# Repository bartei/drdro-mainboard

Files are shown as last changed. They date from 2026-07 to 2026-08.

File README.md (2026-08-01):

# drDRO Mainboard V1.5




Hardware design **and** firmware for the drDRO 5-axis DRO / motion mainboard —
an STM32F411RET6 board that reads up to five quadrature encoder scales, drives a
step/dir servo axis, and talks to the host over RS-485 or Ethernet.

## The board

4-layer, 178 × 76 mm, 24 V supply (LMR33630 → 5 V → AMS1117 3.3 V). Designed in
EasyEDA Pro (`DRDRO Mainboard V1.5.eprj2`); mechanical model in
`drdro-mainboard.step`, enclosure models under `enclosure/`.

| Subsystem | Hardware |
|---|---|
| MCU | STM32F411RET6 @ 100 MHz (16 MHz HSE), SWD debug |
| Encoder inputs | 5 × DB9, differential RS-422 **or** single-ended TTL (AM26LV32E), hardware quadrature on TIM1–TIM5 |
| Host links | RS-485 (SP3485, USART1 @ 115200) and 10/100 Ethernet (WIZnet W5500 on SPI2 — see the 10BASE-T caveat in `firmware/README.md`) |
| Motor outputs | 3 × STEP/DIR + shared ENA through a ULN2003 (M1 is the servo axis) |
| Digital inputs | 6 × opto-isolated (TLP2309) |
| Analog outputs | 2 × 0–10 V (GP8403 12-bit I²C DAC) |
| Expansion | I²C bus exported on every encoder DB9 |

Design docs, pin map and board status live in `docs/` (`STATUS.md` is the
authoritative hardware state; `mcu_pinmap.md` the pin assignment). `h723_variant/`
holds the design study for a future STM32H723 sibling board.

## The firmware

Complete product firmware under `firmware/` — see
[`firmware/README.md`](firmware/README.md) for the full feature list, protocol
description and build instructions. Highlights:

- FreeRTOS application + dual-bank **IAP bootloader** (A/B storage banks,
  copy-on-activate, power-loss-safe settings, rollback).
- One line protocol (`key=value` + CRC framing) served identically over
  **RS-485 and TCP** (default port 5555, ~250 Hz request rate).
- **Firmware updates over Ethernet** (the running app writes the inactive bank)
  or over RS-485 (bootloader YMODEM — also the recovery path), both driven by
  `firmware/tools/dro_update.py`.
- Host-testable protocol core: `pio test -d firmware/app -e native`.

## Building / flashing

```sh
pip install platformio
pio run  -d firmware/app                 # application (Exec region 0x08020000)
pio run  -d firmware/bootloader          # IAP bootloader (sector 0)
pio test -d firmware/app -e native       # protocol unit tests
firmware/tools/build-release.sh          # firmware/dist/ + merged factory image
```

A blank board is flashed once over SWD with `drdro-mainboard-factory.hex`
(bootloader + app merged). After that, updates need no debugger:

```sh
firmware/tools/dro_update.py --net <board-ip> drdro-mainboard-app.bin   # Ethernet
firmware/tools/dro_update.py /dev/ttyUSB0    drdro-mainboard-app.bin   # RS-485
```

The repo ships a devcontainer (`.devcontainer/`) with the full toolchain,
ST-Link/USB passthrough and host networking — see `.devcontainer/README.md`.

## Releases

Versioning and releases are automated with
[python-semantic-release](https://python-semantic-release.readthedocs.io/) from
[Conventional Commits](https://www.conventionalcommits.org/): every push to
`master` runs the test suite and, if there are releasable changes, tags
`vX.Y.Z`, regenerates [`CHANGELOG.md`](CHANGELOG.md), publishes GitHub release
notes and attaches the firmware assets:

| asset | purpose |
|---|---|
| `drdro-mainboard-app.bin` | application image — feed to `dro_update.py` (automated updates) |
| `drdro-mainboard-app.{hex,elf}` | same image for programmers / debugging |
| `drdro-mainboard-bootloader.{bin,hex,elf}` | IAP bootloader (SWD only) |
| `drdro-mainboard-factory.hex` | merged bootloader + app — first flash of a blank board |
| `SHA256SUMS.txt` | asset checksums |

Pushes to a `dev` branch publish `vX.Y.Z-beta.N` prereleases.

## License

GPL-3.0-or-later — see [LICENSE](LICENSE). The firmware descends from the
[drdro-firmware-f4](https://github.com/bartei/drdro-firmware-f4) baseline.

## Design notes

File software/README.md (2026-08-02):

# drDRO Software (drdro-software-f4)

A **Kivy-based Digital Read-Out (DRO) and single-axis controller UI** for rotary tables,
running on Raspberry Pi or desktop (Linux/Windows/macOS). It drives the **drDRO**
STM32F411 control board ([drdro-firmware-f4](https://github.com/bartei/drdro-firmware-f4))
over RS-485 using the firmware's **custom CLI line protocol** (replacing the older Modbus
RTU stack).

This is the successor to **rotary-controller-python (RCP)** — a 1:1 feature port with the
driver layer swapped to the new protocol, board-side persistent settings, and firmware
updates driven over the same RS-485 bus.

> **This repo is in migration setup.** See `docs/migration_design.md` (verbose design) and
> `docs/migration_todo.md` (phased tracker). Implementation begins after the design review.

---

## Features (target — ported 1:1 from RCP)

- Responsive touch UI built with **Kivy**.
- Communicates over **RS-485** with the drDRO board via its line protocol (115200, auto-direction).
- **Configurable axes** — assign hardware scale inputs, apply transforms (identity / sum).
- **Electronic Lead Screw (ELS)** mode for synchronized threading and power feed.
- **Sync mode** with configurable gear ratios for spindle-synchronized movement.
- **Indexing / Jog / DRO** operating modes; pattern calculators (circle / line / rect).
- Customizable display: fonts, colors, metric/imperial/angle formats.
- Contextual RST help on every setting; WiFi (nmcli) and Pi system maintenance screens.
- **New:** STM32 **firmware update + bank management** over RS-485 (YMODEM), and reliance on
  **board-stored settings** instead of re-pushing config on every reconnect.

---

## Requirements

- **Hardware:** drDRO controller board (firmware: `drdro-firmware-f4`), RS-485 interface,
  Raspberry Pi 3/4/5 for Pi deployments.
- **Software:** Python 3.10+, [`uv`](https://docs.astral.sh/uv/).

## Build & run

```bash
uv sync                       # install dependencies
uv run python -m dro.main     # run the app
uv run pytest                 # run tests
uv build                      # build package
```

---

## Project structure (target)

```
dro/
├── main.py                 # Entry point (asyncio + Kivy event loop)
├── app.py                  # MainApp
├── feeds.py                # Feed/thread pitch tables
├── comms/                  # RS-485 line-protocol driver (replaces Modbus)
│   ├── protocol_client.py  # Framed request/response client (get/set/sta/save/load/...)
│   ├── ymodem.py           # YMODEM sender (firmware push)
│   └── updater.py          # Firmware update + bank management orchestration
├── dispatchers/            # Event dispatchers & state (board, axis, input, servo, els, formats, ...)
├── components/             # UI (screens, home/mode bars, popups, widgets, plot, toolbars)
└── utils/                  # platform.py, kv_loader.py, ctype_calc.py
```

---

## Migrating from rotary-controller-python (RCP)

drDRO software is RCP with the communication layer replaced. If you're coming from RCP:

- **Firmware:** requires the new **drDRO firmware** ([drdro-firmware-f4](https://github.com/bartei/drdro-firmware-f4))
  speaking the RS-485 **line protocol** — it does **not** talk to the old Modbus firmware.
- **No Modbus address:** the bus has a single device and no addressing; `config.ini` no longer
  has a `[device] address` key (just `serial_port` + `baudrate`). `minimalmodbus` is replaced by `pyserial`.
- **Board-stored settings:** servo max/accel/jog now live in the board's flash and are read on
  connect (no re-push every reconnect); the UI writes + `save`s them on change. Sync ratios are
  still computed host-side and pushed live.
- **Config location:** settings now live in `~/.config/drdro-software/` (was
  `~/.config/rotary-controller-python/`). Existing RCP YAML files are not auto-migrated — copy
  them over if you want to keep your axis/format configuration.
- **New: firmware updates from the UI** — the Firmware screen flashes board releases over RS-485
  (Setup → Firmware), and lets you pick the boot bank / reboot the board.

## References

- **Firmware & protocol:** [drdro-firmware-f4](https://github.com/bartei/drdro-firmware-f4)
  (`docs/protocol_design.md`, `dualbank_design.md`, `tools/dro_update.py`).
- **Predecessor:** [rotary-controller-python](https://github.com/bartei/rotary-controller-python).

## License

GPL-3.0-or-later. See `LICENSE`.

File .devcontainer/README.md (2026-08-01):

# Dev container — drDRO mainboard V1.5

VS Code dev container for the firmware in `firmware/`: PlatformIO Core + the
`ststm32`/`stm32cube` toolchain (auto-fetched on first build), a host C compiler,
serial terminals, the GitHub CLI, `st-flash` (raw ST-Link flashing), network tools
for the W5500 bring-up, and the **Claude Code CLI** wired to your host login.

Mirrors the `drdro-firmware-f4` container, with the differences noted below.

## Use
Open the folder in VS Code → **Reopen in Container**. The first build warms the
cache (downloads the `arm-none-eabi` toolchain + framework — a few minutes, once;
cached in the `drdro-mainboard-platformio` volume thereafter).

> **This repo root is not a PlatformIO project.** The firmware lives in
> `firmware/`, next to the hardware design files, so every `pio` command needs
> `-d firmware`. `.vscode/tasks.json` wraps the common ones — **Ctrl+Shift+B**
> builds. If you want the PlatformIO *toolbar* (which keys off a `platformio.ini`
> in the workspace root), open the `firmware/` folder directly instead.

| Task | Command |
|---|---|
| Build | `pio run -d firmware/app` (bootloader: `-d firmware/bootloader`) |
| Flash | `pio run -d firmware/app -t upload`  •  or `st-flash write firmware/app/.pio/build/drdro_mainboard_v15/firmware.bin 0x08020000 (app is Exec-linked; blank boards take firmware/factory.hex)` |
| Clean | `pio run -d firmware/app -t clean` |
| Serial  | `tio /dev/ttyUSB0 -b 115200` — RS-485 debug console (needs a transceiver) |
| Ping | `ping <board-ip>` — the container is on the host network |
| Claude  | `claude` — already signed in with your host account |

Host-side protocol unit tests: `pio test -d firmware/app -e native` (68 cases,
HAL/RTOS mocked under firmware/app/test/mocks/).

## Flashing / debugging (ST-Link over USB)
USB device passthrough is **Linux-host only**. The container runs `--privileged`
with host networking and bind-mounts all of `/dev`, so any USB-connected ST-Link
(and USB-serial adapter) is visible — including devices hot-plugged after the
container started.

The `/dev` bind mount only *exposes* the host's device nodes; it does not change
their permissions. So the udev rule must exist on the **host**. `49-stlink.rules`
in this folder is the one in use on this machine (already installed at
`/etc/udev/rules.d/49-stlink.rules`); on a fresh host:

```sh
sudo cp .devcontainer/49-stlink.rules /etc/udev/rules.d/
sudo udevadm control --reload-rules && sudo udevadm trigger
```

PlatformIO's own `99-platformio-udev.rules` works equally well if you prefer it.

`setup.sh` reports ST-Link status at container-create time, so a missing rule or
an unplugged probe is obvious immediately rather than at first flash.

### WSL
The ST-Link must be attached to WSL from Windows first (admin PowerShell):

```powershell
usbipd list
usbipd attach --wsl --busid <BUSID>   # --auto-attach survives replug/probe reset
```

### OpenOCD transport quirk (already handled)
`ststm32@19.4.0` hardcodes `transport select hla_swd`, but the OpenOCD it pins
(0.12) dropped the legacy HLA driver, so a stock `-t upload` fails with
*"Debug adapter doesn't support 'hla_swd' transport"*. `firmware/support/
openocd_swd_transport.py` rewrites that one flag at upload time, so this is
transparent here — no need for the `stlink-tools` fallback. See that script's
header for why the platform pin is kept rather than bumped.

## Claude Code
`claude` is installed in the image (native standalone build, in `~/.local/bin`) and
the container **bind-mounts your host `~/.claude` and `~/.claude.json`**. That means
it shares the host's login (`~/.claude/.credentials.json`), settings, global
`CLAUDE.md`, and memory — no separate `/login` inside the container.

- Sharing works because the container's `vscode` user is uid 1000, matching the host
  user, so the mounted config files are owned correctly.
- `DISABLE_AUTOUPDATER=1` stops the container's claude from self-updating and
  rewriting the shared host config; update Claude on the host as usual.
- Because the config is *shared* (not copied), sessions/history from the container
  land in your host `~/.claude`.

## Ethernet bring-up notes
`--network=host` puts the container on the real LAN, so once the board has its DHCP
lease you can `ping` it and run `tcpdump` against the same segment — both installed.

Remember the hardware finding: **this W5500 only receives at 10 Mbps**, so a
10BASE-T-capable switch must be in the path. Full measurements in
`firmware/README.md`.

## How it's wired
- `Dockerfile` — base image + apt tools (compiler, serial, lrzsz, usbutils,
  **stlink-tools**, **iputils-ping/tcpdump**) and the **Claude Code** native install
  for the `vscode` user.
- `devcontainer.json` — `--privileged` + `--network=host`, `/dev` bind mount, host
  `~/.claude`/`~/.claude.json` bind mounts, and the PlatformIO extension pinned to
  the volume's CLI core.
- `setup.sh` (postCreate) — installs PlatformIO Core to `~/.platformio/penv`, warms
  the build **and pre-fetches `tool-openocd`** (otherwise first discovered at first
  flash), then reports claude / st-flash / ST-Link status.
- `~/.platformio` is the named volume `drdro-mainboard-platformio` — deliberately
  **separate** from the f4 project's `drdro-platformio` so the two cannot disturb
  each other's pinned packages.

## PlatformIO extension note
`platformio-ide.customPATH` points the extension at the CLI core installed in the
`~/.platformio` volume, and `useBuiltinPIOCore=false` stops it from downloading and
installing its *own* core on open — which otherwise races the `setup.sh` install and
triggers the "installing PlatformIO Core…" prompt on every container open.

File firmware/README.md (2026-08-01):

# drDRO mainboard V1.5 — firmware

Full firmware for the **STM32F411RET6** on the DRDRO Mainboard V1.5 (the board in
this repo): PlatformIO + STM32Cube HAL + FreeRTOS. Ported from the proven
`drdro-firmware-f4` baseline (the previous, RS-485-only board) and extended with
this board's hardware: 5 encoder scales, W5500 Ethernet (TCP CLI + network
firmware updates), GP8403 analog outputs, and 6 opto-isolated inputs.

## Layout — two PlatformIO projects + a shared contract

```
firmware/
├── app/          the application  (Exec region 0x08020000, FreeRTOS, all features)
├── bootloader/   IAP bootloader   (sector 0 @ 0x08000000, polled, self-contained)
├── shared/       app<->bootloader contract: Bootloader.h (flash map + handshake),
│                 Settings.h ("DRO2" persisted layout), BlinkCode.h, BoardPins.h
├── tools/        dro_update.py (serial + --net updater), make_factory.py,
│                 build-release.sh
└── reference/    TEMPORARY copy of drdro-firmware-f4 (gitignored, never commit)
```

## Build / flash / test

```sh
pio run  -d firmware/app                    # build the app
pio run  -d firmware/bootloader             # build the bootloader
pio run  -d firmware/app -t upload          # flash the app over ST-Link (SWD)
pio test -d firmware/app -e native          # host-side protocol unit tests (68)
firmware/tools/build-release.sh             # dist/ artifacts + merged factory.hex
```

A blank board gets the merged `factory.hex` (bootloader + app in one image);
after that, updates go through the dual-bank IAP cycle — no ST-Link needed:

```sh
# over Ethernet (the running app writes the inactive bank; ~30 s):
firmware/tools/dro_update.py --net <board-ip> firmware/app/.pio/build/drdro_mainboard_v15/firmware.bin

# over RS-485 (bootloader YMODEM; also the recovery path):
firmware/tools/dro_update.py /dev/ttyUSB0 firmware/app/.pio/build/drdro_mainboard_v15/firmware.bin
```

## Features / interfaces

- **CLI line protocol** — identical wire format on both transports
  (`cmd [args]\r` in; `key=value` lines + `crc=HH` + blank line out; optional
  `*HH` request checksum; empty line repeats the last command):
  - **RS-485**: USART1 @ 115200 8N1, DE on PA11 (asserted per response, released
    on the TC interrupt).
  - **TCP**: port `net.port` (default **5555**), one client at a time. DHCP by
    default; static IP via `net.dhcp=0` + `net.cfg.*` (applied at next boot).
- **Commands**: `sta get set settings save load bank rollback version help
  update reset dout fw.begin fw.status fw.commit fw.abort`
- **Registry**: `scales.pos/speed/num/den/sync/filt/dir` (×5),
  `servo.max/acc/jog/idx/mode/pos/speed/tgt`, `din.state/cnt/deb`,
  `aout.raw` (×2, 0..4095 = 0..10 V), `net.*`, `diag.cycles/interval/cycmax/uptime`
  (cycle counts are DWT ticks @ 100 MHz = 10 ns; `set diag.cycmax 0` re-arms the
  worst-case hold; uptime as `<days>d<HH>:<MM>:<SS>`).
- **Encoders**: 5 hardware-quadrature scales on TIM1..TIM5. The AM26LV32E
  receiver inversion is fixed in `Scales.c` (IC1 polarity); `scales.dir` is the
  user-level flip.
- **Motion**: single step/dir servo axis (M1, TIM9 100 kHz RAM-resident ISR —
  survives flash writes); shared ENA; M2/M3 pins exercisable via `dout`.
- **Updates**: dual-bank copy-on-activate (see `shared/Bootloader.h` for the
  flash map). Ethernet updates stream into the inactive bank on port
  `net.port+1` and only `fw.commit` (full-size + CRC32 + vector checks) can
  activate it; the UART-only bootloader (YMODEM) is the recovery path.
- **LED** (PA12): blink codes — 1 app running / 2 bootloader / 3 network down /
  4 W5500 error / 5 flash fault (`shared/BlinkCode.h`).

## Hardware caveat

The W5500 on this board only *receives* at **10BASE-T** (verified per-mode on
hardware; see `app/README.bringup.md` for the measurement). `Net.c` forces
10M-half first and a 10 Mbps-capable switch is required.

## Baseline / history

- `app/README.bringup.md` — the original Ethernet bring-up notes (clock/SPI/
  DHCP verification, PHY-mode measurements, MACRAW self-test).
- The `drdro-firmware-f4` project is the design baseline; its docs
  (`protocol_design.md`, `dualbank_design.md`) still describe the protocol and
  bank machinery authoritatively. Differences here: 5 scales (registry arrays
  are 5 wide), settings magic **DRO2** (fresh payload, same frozen core), DE
  pin handling, TCP transport, `dout`/`fw.*`/`din.*`/`aout.*`/`net.*`, and a
  version-stamped bootloader (`BL_VERSION`).

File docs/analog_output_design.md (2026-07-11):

# Analog outputs — 2× 0–10 V for VFD speed reference

## Goal
Add **two 0–10 V analog outputs** to command spindle/motor RPM on variable-frequency
drives (VFD analog speed reference). Decided **2026-07-10**. **4–20 mA was
considered and dropped** (user, 2026-07-10) — 0–10 V only. Non-isolated (board and
VFD share the cabinet 0 V), cost/JLCPCB-stock prioritized.

## Part of record
**U20 (next free designator — confirm in EDA) = GP8403-F50-NF-EW** (Guestgood /
客益微), ESSOP-10-150mil, **JLCPCB/LCSC C3152007** (~$1.70@1, ~4.9k stock 2026-07-10
— re-verify JLCPCB SMT stock/part-class at order time, changes daily).

Dual 12-bit I²C→analog-voltage DAC: **one chip = both channels**. 0–5 V / 0–10 V
range software-selectable. 0.5% output error (0.2% "H" grade exists if ever needed).
Response time ~100–200 µs. Each VOUT sources up to 20 mA.

### Why this part
- **STM32F411 has no internal DAC** (unlike F410/F407) — an external device is
  required no matter what; this is the tidiest one.
- **24 V-native**: VCC range 10–40 V (nom 12 V, tested at 24 V). Runs straight off
  the board's existing 24 V rail — no new supply, no op-amp gain stage, no
  PWM+filter ripple/settling tuning.
- Dual channel in one small SO-package; cheap and well-stocked on JLCPCB.
- Alternatives rejected: **DAC8760/AD5420** (does 0–10 V *and* 4–20 mA in one chip,
  but ~2–3× cost + extended-part stock risk — overkill once 4–20 mA was dropped);
  **PWM (TIM9 CH1/CH2 = PA2/PA3) + RC filter + op-amp** (cheapest silicon but adds a
  filter+RRO-op-amp stage per channel, ripple/settling trade, more board area than
  the GP8403 for ~the same cost).

## Supply
- **VCC ← 24 V rail.** Add local decoupling: 0.1 µF + 10 µF at the pin. The raw 24 V
  bus carries motor-driver switching noise → add a **series ~10 Ω (or ferrite) + 10 µF
  RC** feeding the DAC VCC to keep that noise off the reference. (5 V/3V3 rails are
  too low — the part needs ≥10 V.)
- **V5V pin**: internal 5 V LDO output — needs an external **≥1 µF** cap to GND
  (datasheet requirement).

## Digital interface (I²C) — DECIDED: shared I²C1 expansion bus (2026-07-10)
- **On the existing I²C1 expansion bus** (PB8 SCL / PB9 SDA), shared with the five
  DB9 connectors' pin 5/9. U20-1 SCLK→SCL, U20-2 SDA→SDA. **No new GPIO used.**
  - Pull-ups: **existing R74 (SCL) / R14 (SDA) 4.7 kΩ → 3V3** — reused, none added.
  - I²C logic high 2.7–5.5 V → 3.3 V MCU drive is in spec.
  - **Address = 0x58** (A0/A1/A2 all strapped to GND). **Reserve 0x58** — no future
    DB9-bus expansion device may reuse it.
  - Trade-off accepted: the AO DAC shares a bus routed out to 5 external connectors,
    so a field short on a DB9 pin 5/9 could disturb DAC comms. Acceptable — the DAC
    holds its last output and a 0–10 V speed ref is not safety-critical here.
- **Rejected alternative:** dedicated bit-bang bus on 2 spare GPIOs (PC8/PC9) for
  isolation from the external bus. Cleaner electrically but costs 2 pins + firmware;
  user chose the shared bus for simplicity (pull-ups already present).

## Analog outputs
- VOUT0 → **AO0**, VOUT1 → **AO1** (as-built net names).
- **Per output**: **1 µF** cap to GND (C42/C43) **+ 12 V unidirectional TVS to GND**
  (**SMAJ12A**, JLCPCB **C113957**, SMA/DO-214AC — same TVS family already used on
  the board; cathode→signal, anode→GND). 12 V standoff clears the 0–10 V signal and
  clamps (~19.9 V) well under the 40 V abs-max. **Cap value per the official (Chinese)
  datasheet pin table: 1 µF on each VOUT, >1 µF on V5V** — as-built 1 µF is correct.
  (The third-party English "StanStrong" translation says 10 µF; it's wrong — official
  source governs.)
- **47 Ω series R** to the terminal for short/surge hardening (R75/R76) — VFD analog
  inputs are high-Z (≥10 kΩ typ) so the divider error is negligible. TVS + cap sit on
  the DAC side, series R between them and the connector.
- **Connector**: **CN9**, 4-pos terminal block, **WJ15EDGRC-3.81-4P** (matches
  existing connectors) — **AO0 / AO1 / GND / GND** (pin4/3 = outputs, pin1/2 = COM).
  Wiring to VFD: AOx → analog-in (AI/VI), COM → analog-common (ACM/GND). Non-isolated:
  COM = board GND.

## Range / resolution / accuracy
0–10 V, 12-bit → **2.44 mV/LSB**, 0.5% total error, 50 ppm/°C, ~200 µs settle.
Far finer than any VFD speed-reference needs.

## Firmware notes
- **Set 0–10 V mode once** at boot: config register (addr byte **0x01**), write
  **0x11** (0x00 = 0–5 V). Optionally persist to on-chip NVM (§3.3.7) so it survives
  power-down.
- **Write a channel**: VOUT0 via command **0x02**, VOUT1 via **0x04**; 12-bit code
  as two bytes (low byte first, low 4 bits of the low byte ignored — i.e. code is
  left-justified). Output: **VOUT = DATA/0xFFF × 10 V**.
- Scale spindle RPM setpoint → 12-bit code per VFD's max-RPM-at-10 V setting.

## Board impact (as-built, `Netlist_Schematic1_2026-07-10.net`)
+1 IC (U20 GP8403), passives: C42/C43 1 µF out, D5/D6 SMAJ12A TVS, R75/R76 47 Ω
series, C45 1 µF V5V (+ VCC decoupling), +1 terminal block (CN9). **0 new MCU GPIO**
(shares I²C1 PB8/PB9; pull-ups R14/R74 reused). Component count 177 → **189**.

## AS-BUILT — verified 2026-07-10 (netlist review)
U20 = GP8403-TC50-EW (C3152007). VCC→VIN (24 V, D2/U2 source); GND + **EP→GND** ✓;
SCLK/SDA→SCL/SDA (I²C1 + DB9 pin5/9 + R74/R14); **A0/A1/A2→GND = addr 0x58**;
V5V→C45(1 µF); VOUT0→AO0, VOUT1→AO1, each C(1 µF)+SMAJ12A(→GND)+47 Ω→CN9
(AO0/AO1/GND/GND). No dangling nets; 3V3/5V/VIN all sourced. **Clean.**
Open (optional): local 0.1 µF + RC/ferrite on VCC to keep 24 V-bus switching noise
off the reference; reserve I²C **0x58** against future DB9-bus devices.

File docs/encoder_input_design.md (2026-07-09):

# Encoder input stage — universal single-ended + differential

## Goal
Accept BOTH single-ended TTL and differential RS-422 encoder/scale inputs on
the same DB9, with **no mux and no mode selection** — "just works" like the
cheap Chinese DROs. Approved 2026-07-04.

## AS-BUILT vs TARGET (status 2026-07-09)
**As built** (netlist `Netlist_PCB1_2026-07-09.net`, verified): the mux is gone,
the biased-receiver technique is in, and the **per-DB9 split is DONE — 5 quad
receivers, one AM26LV32EIDR at each connector, A/B only**:
- U7 = J1/ENC1, U8 = J2/ENC2, U9 = J3/ENC3, U10 = J4/ENC4, U11 = J5/ENC5
- Per line: 2.2k pull-up on A+/B+, 2.2k/2.2k divider on A−/B− (~2.5V ref), no term
- Receivers enabled (pin4/G = 3V3); each chip's 2 spare channels have inputs tied
  to a defined level, outputs left open
- Receiver outputs direct to MCU (PA8/9, PA5/PB3, PA6/7, PB6/7, PA0/1 → TIM1–5).
  **No index-Z wired yet.**

**Remaining vs design of record:** only **index-Z** is still to add (A/B/**Z** +
spare per the "Modularity" section below). Reuse a spare receiver channel per chip
for Z; DB9 pin 6 is the only free connector pin (see Z-routing constraint).

**Z-routing constraint:** each DB9 (DS1037-09) has only **pin 6** free — pins
5/9 carry the I²C SCL/SDA expansion bus. So a *differential* Z (Z+/Z−) has no
room unless I²C is dropped/moved; a **single-ended Z on pin 6** is the drop-in
option. MCU side is not the limit: 11 free GPIOs (PC13/14/15, PA2/3/4, PC8/9,
PD2, PB4/5) — ample for 5 Z inputs. Tracker: `encoder_input_todo.md`.

## Decision
Replace the current dual-path front-end (AM26LV32E differential receiver +
NC7SZ157 mux + TTL_SEL) with a **single universal biased differential
receiver** per channel, no termination, no mux.

### The technique (industry-standard; see references)
A differential line receiver reads single-ended by biasing the complementary
(−) input to a fixed reference at **half the encoder supply (2.5 V for 5 V
scales)**, per Emerson/Control Techniques CTTN #155 ("bias the complementary
channels... to ½ of the encoder supply") and confirmed by TouchDRO ("RS-422
line receivers also handle single-ended quadrature inputs cleanly").

Per differential pair (e.g. A+/A−):
- **A+ → pull-up to 5 V** (fail-safe high when idle; also serves open-collector
  single-ended scales)
- **A− → divider to ~2.5 V reference** (½ of the 5 V scale supply)
- **NO termination** (the old 120 Ω is what collapsed the reference and forced
  the mux; low-Z termination breaks single-ended — CTTN #155 disables term in
  this mode)
- optional **~150 Ω series** resistor from the DB9 pin for ESD/fault protection

Behaviour, all with one input, no switching:
| Scale | A+ | A− | Receiver sees | Output |
|---|---|---|---|---|
| Single-ended | 0–5 V signal | 2.5 V ref | signal vs 2.5 V | clean ✓ |
| Differential | driven | driven (low-Z driver **overrides** the kΩ bias) | true differential | clean, full CMRR ✓ |
| Disconnected | pulled to 5 V | 2.5 V | +2.5 V | defined HIGH → no phantom counts ✓ |

The differential driver "takes over" the − line because the bias is high-Z
(kΩ) and the line driver is low-Z. That's the whole trick.

### Receiver part: AM26LV32E (keep) — confirmed right
Quad differential line receiver, already in the design. Datasheet SLLS849E:
- A/B input abs-max **±14 V** → rugged for external DB9 (miswire/ESD/any scale)
- VIH to **5.5 V**, common-mode **−7…+7 V** → handles 2.5 V bias + 5 V swing
- **3.3 V supply, 3.3 V logic output** → safe for ALL MCU pins incl. **PA0
  (ENC5A), which is 3.3 V-only/not 5 V-tolerant**. A 5 V receiver (AM26C32/
  26LS32) would over-drive PA0 → rejected for that reason.
- Failsafe ("E" variant).

### Modularity: one quad receiver per DB9 connector
Go **one AM26LV32E per DB9** (5 chips vs current 3):
- Self-contained per-axis block → copy-paste schematic + PCB, better layout.
- Receive differential AT the connector → best signal integrity.
- Per-axis fault isolation.
- Quad = A + B + **Z (index)** + 1 spare → future-proofs the reference mark
  (DRO homing) with no redesign. Currently only A/B wired.
- Tie spare channel inputs to a defined level.

### Open detail — bias divider vs receiver input R
AM26LV32E input resistance is 4–17 kΩ, which loads the 2.5 V divider (a naive
10 k/10 k sags to ~1.9 V). Fix when specing values: use a stiffer divider
(~2.2 k/2.2 k) OR one shared buffered 2.5 V reference fed through per-channel
series R. Reference anywhere ~2.0–2.5 V is fine (0–5 V swing gives margin).

## Parts removed vs current design
- NC7SZ157 muxes (U22–U31, all 10) — deleted
- 1 kΩ I0 series resistors (R78 ×10) — deleted
- 120 Ω terminations (R47 ×10) — deleted
- TTL_SEL GPIO (PA4) — freed
- Route AM26LV32E outputs directly to the MCU encoder pins.

## Caveat (inherent to single-ended, per CTTN #155)
Single-ended has no common-mode rejection on that channel → more noise-
sensitive than differential. Good grounding/shielding matters. A differential
scale on the same input still gets full noise rejection. This is the exact
trade-off cheap DROs accept.

## References
- Emerson/Control Techniques CTTN #155 "Accommodating Single Ended Encoders"
- TouchDRO glass-scale resources (touchdro.com)
- TI AM26LV32E datasheet SLLS849E

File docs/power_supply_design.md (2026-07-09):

# Power supply — 24V → 5V buck stage

## Decision

Replace the LM2596-5.0 with a **TI LMR33630ADDAR** synchronous buck converter
(HSOIC-8 PowerPAD, adjustable output, 400 kHz).

## Why this part

- **3.8–36 V input range** — large margin above the 24 V nominal rail. The
  board is a motion-control mainboard (rotary/servo), so the 24 V bus likely
  carries switching noise from motor drivers; 36 V abs-max headroom absorbs
  that without derating the part right at its ceiling (unlike parts rated
  only to 24–28 V).
- **Synchronous topology** (no catch diode) — peak efficiency >95%, far above
  the LM2596's typical ~75–85% at 24V→5V/2A.
- **3 A rated device vs. 2 A max load** — ~33% continuous-current headroom,
  keeps thermal/transient margin comfortable.
- **400 kHz switching** allows an 8–10 µH inductor and ceramic-only output
  caps, vs. the LM2596's typical 33–100 µH inductor + electrolytic bulk caps.
  Meaningful footprint reduction.
- **Internally compensated** — no external compensation network, minimal
  part count.
- Confirmed **not deprecated**, in active production.

## Stock verification (checked 2026-07-03, JLCPCB SMT-assembly inventory — verify again before ordering, this changes daily)

| Part | Role | JLCPCB # | Stock | Class | Notes |
|---|---|---|---|---|---|
| LMR33630ADDAR (TI) | Buck controller | C841384 | 9,995 | Extended | 3.8–36V in, 3A, 400kHz, HSOIC-8 PowerPAD |
| CYA0630-10UH (SHOU HAN) | Power inductor | C5189958 | 66,769 | Extended | 10µH, 4A rated / 5.5A sat, 71mΩ DCR, 7.2×6.6mm shielded |
| TPS54331DR (TI) | Fallback controller (alt) | C9865 | 94,107 | Extended | Non-sync alt, see below |

Other LMR33630 variants checked and rejected for this design:
- `LMR33630BDDAR` (1.4MHz) — C544370, only 1,835 units. Usable if board space
  later forces a smaller inductor, but thinner stock margin.
- `LMR33630CDDA` (2.1MHz) — out of stock at time of check.
- `MP2315`/`MP2338` (MPS) — not carried on LCSC/JLCPCB under the genuine MPS
  brand, or Vin range (≤24-28V) leaves no headroom over the 24V nominal rail.
- CENKER `CKCS5040-8.2uH/M` inductor — only 410 units and flagged "not
  recommended for new designs" on JLCPCB. Avoided.

## Design equations used (LMR33630 datasheet §9.2.2, SNVSAN3F)

- FB divider: `RFBB = RFBT / (VOUT/VREF − 1)`, VREF = 1.0 V nominal.
  Base point RFBT = 100 kΩ → RFBB = 24.9 kΩ for VOUT = 5 V (both 1%). This
  was superseded by the adjustable divider below, kept here for reference.
- Adjustable divider (4.8–5.2V range): solved the two endpoint equations
  simultaneously against a 2kΩ trim span (`RFBB_min = 9.5·Rtrim`,
  `RFBT = 4.2·RFBB_min`) → **RFBT = 80.6kΩ**, **RFBB1 (fixed) = 19.1kΩ**,
  **RV1 = 2kΩ 25-turn trimmer** (Bourns 3296W-1-202LF, THT SIP-3, JLCPCB
  C83684, 12,135 in stock). Trim at 0Ω → ~5.22V; trim at 2kΩ → ~4.82V —
  brackets the requested 4.8–5.2V with margin so setpoints aren't at the
  pot's end-stops. ~16mV/turn resolution. See wiring step 6 below for how
  the trimmer is wired as a rheostat (not a bare 3-terminal divider) so a
  worn/lost wiper contact can't float FB.
- Inductor: `L = (VIN−VOUT)/(fSW·K·IOUTmax) · VOUT/VIN`, K = 0.3 ripple
  factor, **IOUTmax = 3 A (device rating, not the 2A application max — the
  datasheet explicitly says to use the device max when the app's max load is
  much smaller)** → L ≈ 8.1 µH. Nearest well-stocked standard value used:
  **10 µH** (6.8 µH is also acceptable; floor per eq. 5 is
  `LMIN ≥ 0.28·VOUT/fSW` ≈ 3.5 µH).
- Output cap: datasheet's quick-reference table gives 4×22µF for
  VOUT=5V/400kHz row regardless of Vin.
- Input cap: "preferably rated for twice the max input voltage" → 50V-rated
  ceramics for a 24V nominal rail. Two 10µF in parallel (rather than a single
  10µF) to offset DC-bias capacitance derating at 24V bias.

## Wiring (HSOIC-8 PowerPAD pinout: 1 PGND, 2 VIN, 3 EN, 4 PG, 5 FB, 6 VCC, 7 BOOT, 8 SW, thermal pad = AGND)

1. 24V rail → **CIN bank**: 2×10µF 50V X7R ceramic (1210 case) in parallel +
   **CHF** 220nF 50V X7R, both directly across VIN(2)/PGND(1), placed as
   close to the pins as physically possible.
2. VIN(2) → **EN(3)** tied directly together. No external UVLO divider
   needed — regulator follows the 24V rail. (If upstream sequencing ever
   needs a delayed enable, add the RENT/RENB divider per datasheet §9.2.2.10;
   not needed for this design.)
3. **SW(8)** → **L1** (10µH, CYA0630-10UH) → VOUT node.
4. **BOOT(7)** ← 100nF ceramic (≥10V rating, e.g. 25V X7R) → **SW(8)**.
5. VOUT node → **COUT bank**: 4×22µF 16V X5R/X7R ceramic (1210 case) to AGND,
   plus one small 100nF placed at the point of load for HF noise
   suppression.
6. VOUT node → **RFBT** (80.6kΩ 1%) → **FB(5)**. From FB(5) → **RFBB1**
   (19.1kΩ 1%, fixed) → **RV1 pin 1** (2kΩ 25-turn trimmer, 3296W-1-202LF).
   **RV1 pin 2 (wiper) shorted to pin 3**; pin 3 → AGND. Wiring the trimmer
   as a 2-terminal rheostat (rather than tapping FB off the wiper directly)
   means a worn/lost wiper contact reverts to the trimmer's fixed end-to-end
   resistance instead of floating FB open (FB must never float per
   datasheet). Route the FB trace short and away from the SW node/inductor.
   Dab of varnish/thread-lock on the trimmer screw post-calibration
   recommended given this board sees motion/vibration.
7. **VCC(6)** → **CVCC** 1µF 16V ceramic → AGND. Do not load VCC with
   external circuitry.
8. **PG(4)**: open-drain flag, optional. Leave floating if unused, or pull to
   VCC(6) through 100kΩ to get a "5V good" signal into an MCU GPIO.
9. **PGND(1)** and the exposed **thermal pad (AGND)** both return to the same
   ground pour immediately beside the IC. Solder the thermal pad to the
   ground plane with a via array — dissipation is low (<1W at 2A/~95%
   efficiency) so this is mostly a formality, not a hard thermal requirement.
10. Keep the VIN→SW→L1→COUT→PGND hot loop physically tight (standard buck
    layout practice) to minimize EMI radiation.

`CFF` (feed-forward cap across RFBT) is **not populated** — only needed at
RFBT > 100kΩ or specific transient-response tuning, not required here.

## Alternates for stock resilience

- **LMR33630BDDAR** (1.4MHz, C544370) — same pin/BOM structure, smaller
  inductor (2.2–4.7µH) if board space later becomes the dominant constraint.
  Re-check stock before switching (1,835 units at last check).
- **TPS54331DR** (non-synchronous, C9865, 94,107 in stock) — very deep stock
  fallback if the whole LMR33630 family craters. Needs an external Schottky
  catch diode (e.g. SS34) between SW and PGND, slightly lower efficiency,
  and only 28V abs-max input (less headroom than the 36V LMR33630).

## RS485 transceiver — PART CHANGE (2026-07-09)
**U5 SIT3088ETK (DFN-8) is out of stock at JLCPCB.** Replacement: **SP3485EN-L/TR
(JLCPCB C8963, SOIC-8, 3.3V, 10Mbps)** — ~191k in stock, ~$0.30. Pin-identical to
the SIT3088 (`1 RO, 2 RE̅, 3 DE, 4 DI, 5 GND, 6 A, 7 B, 8 VCC`), so it's an
electrical drop-in: PA11 GPIO-DE, R9/R10 680Ω bias, R12 120Ω term all unchanged.
Only action: change the U5 footprint DFN-8→SOIC-8 (SOIC-8 has no exposed pad, so
the "EP→GND" layout item disappears). 10Mbps SP3485 matches the design's USART1
ceiling. Alt if ever needed: MAX3485ESA+T (C18148, ~11k stock, ~5× the price).
Re-confirm stock at order time (changes daily). Historical auto-direction analysis
below is superseded by the GPIO-DE topology (see round 3/4 notes).

## RS485 auto-direction circuit — analysis + max speed (2026-07-04)

**Topology (correct).** U5 = SIT3088ETK (14 Mbps half-duplex, VCC=3V3).
DE and RE# are tied together (net $5N277). Q1 (BC847B): base ← R1(470Ω) ←
UART1_TX; emitter → GND; collector → $5N277. R2(2.2k) pulls $5N277 → 3V3.
DI is tied directly to UART1_TX.
- TX idle/mark (high): Q1 on → $5N277 low → DE=0 (driver off), RE#=0 (RX on).
  Bus mark held **passively by the fail-safe bias** (R57/R63/R62 = 120Ω).
- TX space (low): Q1 off → R2 pulls $5N277 high → DE=1 (driver on), drives space.
This is the classic TX-sensing single-NPN auto-DE. It works. Note DE=RE# are
tied, so the (DE=0,RE#=1) shutdown state is never entered — no shutdown glitch.

**Reconciles the earlier "120Ω bias too heavy" flag:** because the driver is
OFF during every mark, the mark level is set entirely by the bias network, so
strong 120Ω bias is actually *wanted* here (fast, solid mark recovery). The
SP3088E driver is rated to drive 54Ω (VOD 1.5V min), so it still makes
compliant space levels against the 120Ω bias+term load. **Keep 120Ω if
staying with auto-direction;** only raise R57/R63 to ~560–680Ω if switching to
an always-enabled / GPIO-DE driver.

**Speed limiter = the auto-direction loop delay, not the transceiver.**
Enable delay (TX-fall → driver actively driving the space):
- Q1 storage time: R1=470Ω over-drives the base (Ib≈5.5mA to sink only
  ~1.5mA of R2 current → forced β≈0.27, *deep* saturation) → long storage
  time, ~200–400ns. This is the dominant, least-controlled term.
- R2·C node charge to VIH(2.0V): 2.2k × ~22pF ≈ 45ns.
- SIT3088 driver enable: tens of ns (fast part).
→ total enable ≈ **~300–450ns**. Disable (Q1 on, active pulldown) is faster,
~100–150ns. Every UART frame's start bit is a space needing this enable, so
the enable delay must stay a small fraction of one bit time.

**Practical max signaling rate with the circuit as drawn:**
| Baud | Bit time | Enable delay as % of bit | Verdict |
|---|---|---|---|
| 115.2 kbps | 8.68µs | ~4% | rock solid |
| 250 kbps | 4.0µs | ~9% | reliable |
| 500 kbps | 2.0µs | ~18% | marginal (short/clean links only) |
| ≥1 Mbps | ≤1.0µs | ≥35% | not reliable |
So: **use ≤250 kbps; treat 500 kbps as the marginal ceiling; don't rely on
≥1 Mbps.** The 14 Mbps transceiver is ~30–50× underutilized.

**To go faster (if needed):**
1. Cheap: raise R1 to ~4.7–10k (cuts base over-drive → shorter storage time),
   add a ~100pF speed-up cap across R1, optionally a 10k Q1 base-emitter
   resistor. Pushes the marginal ceiling toward ~1 Mbps.
2. Best: drop the transistor and drive DE/RE# from a spare STM32 GPIO
   (assert before TX, deassert on the USART TC "transmission complete" flag).
   Deterministic, unlocks the transceiver's full rate. Note the F411 USART is
   the older IP **without** the hardware Driver-Enable (DEM) feature of
   F0/F3/F7/L4 — so it's a firmware-toggled GPIO, timed off TC.

## Out of scope

Assumes the upstream 24V input already has reverse-polarity/TVS protection
elsewhere on the board; this stage starts at the local 24V net. (Confirmed
present in the netlist review below: D2 TVS + U3 PPTC fuse + D3 series
Schottky, dedicated to this regulator's input.)

## Netlist review findings (2026-07-03, Netlist_Schematic1_2026-07-03.net)

Reviewed with the netlist-review skill (151 components, 137 nets, no
board-wide dangling nets) plus manual trace of every net touching U1.

**🔴 Critical — U1 PGND (pin 1) not tied to system ground.** Net `$2N4625`
has only 2 members: `U1-1 (PGND)` and `R3-1`. It never joins the main `GND`
net (95 pins — EP pad, all cap grounds, etc). The switching-current return
path is open; the regulator cannot function as wired. Fix: wire PGND
directly to GND, at the same local ground node as the input/output cap
returns and the EP pad.

**🔴 Critical (same area) — R3 (100kΩ, C149504) wired VCC→PGND instead of
VCC→PG.** Value matches the datasheet's own PG-pullup recommendation exactly,
but it landed on the wrong net — PG (U1 pin 4) is completely floating
elsewhere. Either move R3's second leg to PG(4) and route PG onward (if the
power-good flag is wanted, e.g. to the STM32), or delete R3 (harmless as
wired, but does nothing useful). Doesn't substitute for the PGND fix above.

**🟠 Verify — FB trim range shifted down from target.** As-built: RFBT =
R31(51k)+R29(30k) = 81k; RFBB = R32(2k trim)+R30(20k) = 20–22k (20k basic
substituted for the exact 19.1k calculated earlier). Range computes to
~4.68–5.05V vs. the ~4.82–5.22V originally targeted. Range isn't critical per
requirements, so left as-is.
CORRECTION (round 3): an earlier version of this note said "swap R30 to
22–24k to recenter nearer 5.00V" — that is BACKWARDS. VOUT = VREF·(1+RFBT/RFBB),
so INCREASING the bottom resistor RFBB LOWERS VOUT. To recenter HIGHER, make
RFBB smaller or RFBT larger. See round-3 findings for the correct fix.

### Round 4 (2026-07-04) — round-3 fixes verified + speed/SPI questions

Verified `Netlist_Schematic1_2026-07-04 (1).net` (142 comp / 130 nets, **no
dangling nets**). All round-3 items resolved:
- ✅ **FB divider on target:** top now R31(51k)+R4(33k)=84k, bottom R2(20k)+
  R32(2k trim) → **VOUT 4.82–5.20V** (exactly the requested window).
- ✅ **UART_DE pull-down added:** R1=10k to GND (defaults to RX at power-up).
- ✅ **Activity-LED circuit removed cleanly** (no orphaned nets).
- Buck (U1: PGND+EP on GND, SW→L) and RS485 (U5, bias R28/R30=680Ω, term
  R33=120Ω) intact after tool re-annotation.

**RS485 max speed with GPIO-DE circuit.** Driver now enabled for the whole
frame (mark + space actively driven), so the auto-direction per-bit limit is
gone. Bounds: transceiver SIT3088E = 14 Mbps; USART1 is on APB2 (100 MHz) →
max baud = fPCLK2/8 = **12.5 Mbps** (OVER8). 10 Mbps → USARTDIV=1.25, exactly
representable → **0% baud error**. So 10 Mbps is clean; ceiling ~12.5 Mbps
(MCU), then 14 Mbps (transceiver). Requires SYSCLK=100MHz + OVER8=1; DE
deassert via USART TC ISR (adds ~2–3 bit-times turnaround, not a throughput
limit). Cable ≤ ~10–12 m at 10 Mbps, both ends terminated 120Ω.
Confirmed pin mapping (ST DS Table 8): PA15=USART1_TX, PA10=USART1_RX,
PA11(DE)=plain GPIO (also USART1_CTS, unused as such).

**Spare SPI bus: SPI2 fully available.** PB12/PB13/PB14/PB15 all free =
SPI2 NSS/SCK/MISO/MOSI (AF5). SPI2 on APB1 (50 MHz) → up to 25 Mbit/s SCK.
16 free GPIOs total (PC0-3, PC6-9, PC14-15, PA2-3, PB12-15) for CS lines /
more devices. Handy alts among them: PC6/PC7=USART6, PA2/PA3=USART2.

**Still-open from round 2 (not yet addressed):**
- 🟠 VCAP C16 still **10µF** — change to 2.2µF (STM32F411 spec).
- 🟠 Decoupling coverage (~8 caps for the logic ICs) — verify 100nF/IC.
- 🔍 U5 SIT3088 EP pad → GND; crystal load caps vs CL.
- ⚪ ISO_IN pull-ups (internal), U16 unused RX inputs, NRST cap.

### Round 3 (2026-07-04) — RS485 DE→MCU + RJ45 removal (Netlist_..._2026-07-04.net)

Reviewed the updated export (147 comp / 138 nets).

**✅ DE control moved to MCU (correct):** Q1/R1/R2 auto-direction removed;
`UART_DE` = PA11 (U10-44) + U5 DE(3) + RE#(2). DI→UART_TX (PA15), RO→UART_RX
(PA10). This is the 10 Mbps-capable topology. USART1 is on APB2 (100MHz) so
it can clock 10 Mbps; drive PA11 high before TX, deassert in the USART TC ISR.

**✅ RS485 bias/termination correctly re-done** (coupled change): old 120Ω
R57/R62/R63 replaced by R28=680Ω (A→3V3 bias), R30=680Ω (B→GND bias),
R33=120Ω (A–B termination). Right values for an always-driven bus. Note
designators reshuffled by the tool (RS485 bias now R28/R30/R33; FB bottom
resistor is now R27).

**✅ RJ45 (SERIAL) removed** — intended by user (SWD still available on the
5-pin SWD header; RS485 now on CN2).

**🔴 FB divider now can't reach 5.0V — regression from the backwards advice
above.** Bottom resistor was changed 20k → **R27=22k**, so RFBB = 22–24k with
RFBT=81k → VOUT ≈ **4.38–4.68V**. The rail can no longer be set to 5.0V.
Fix (bottom resistor must go DOWN, not up):
- Minimal (1 change): R27 22k → **20k** → 4.68–5.05V (reaches ~5.0V).
- On-target (2 changes): R27 → **20k** AND R29 30k → **33k** (RFBT=84k) →
  **4.82–5.20V**, exactly the requested window. All basic 0805 (20k C4328,
  33k C17633, 51k C17737).

**🟠 UART_DE has no pull-down** — add ~10k from UART_DE to GND so DE defaults
to receive at power-up before firmware drives PA11 (prevents bus contention
during boot/reset).

**⚪ Activity-LED circuit orphaned by the net rename** (user already fixing):
4 dangling nets — UART1_TX(R4), UART1_RX(R66), TX_LED(R64), RX_LED(R65).
Q2/Q3 (MMBT5401) TX/RX activity drivers lost their signal when UART1_*→UART_*.
If keeping the LEDs: move R4→UART_TX, R66→UART_RX and reconnect TX/RX_LED to
the indicators. If dropping them: delete Q2, Q3, R4, R64, R65, R66.

### Round 2 (2026-07-04) — corrections verified + full-board sweep

**Both prior criticals confirmed fixed:** U1 PGND (pin 1) now on `GND`; EP
pad on `GND`; R3 (100k) now VCC→PG (pin 4), PG no longer floating. Power
stage otherwise unchanged and correct.

Extended the review to the whole board (151 comp / 137 nets, no dangling
nets). Architecture: STM32F411 + 3× AM26LV32 diff-encoder receivers + 10×
NC7SZ157 muxes (TTL-vs-differential select per channel via TTL_SEL) + 6×
TLP2309 opto-isolated inputs + SIT3088 RS485 (auto-direction via Q1) + ULN2003
STEP/DIR/ENA driver. No new critical/board-killer defects. Open items:

- 🟠 **VCAP cap C16 = 10µF — STM32F411 spec is 2.2µF.** Oversized cap on the
  internal-LDO pin risks stability/startup margin. Change to 2.2µF X7R.
- 🟠 **3V3 decoupling looks light:** ~8 bypass caps for ~15 logic ICs (MCU 4
  rails + 3 receivers + 10 muxes + RS485). Ensure a local 100nF per IC,
  especially the 10 NC7SZ157 muxes; verify on layout.
- 🔍 **RS485 fail-safe bias R57/R63 = 120Ω** (same as the 120Ω termination
  R62). Standard bias is 560–680Ω; at 120Ω the idle bias draws ~9mA and the
  combined bias+termination load (~48Ω with a far-end term) may exceed the
  SIT3088 driver, dropping VOD below the 1.5V RS485 minimum. Keep R62=120Ω;
  raise R57/R63 to ~560–680Ω unless the driver spec proves 120Ω is safe.
- 🔍 **U5 (SIT3088, DFN-8) exposed pad** — confirm EP tied to GND on layout
  (invisible in netlist).
- 🔍 **Crystal load caps C18/C19 = 12pF** — verify against X1's CL (≈10pF
  target → ~9–12pF caps depending on stray); currently plausible.
- ⚪ **ISO_IN1–6 have no external pull-up** — rely on STM32 internal pull-ups
  (TLP2309 open-collector output; indicator LED cathode on each node). Works
  if firmware enables pull-ups; add explicit 10k to 3V3 for a defined
  power-up state + noise immunity if desired.
- ⚪ **ULN2003 STEP/DIR/ENA outputs** pull up through an activity LED + 1.5k
  to 5V (weak, LED-drop-reduced high). Fine for opto/high-Z stepper-driver
  inputs; verify adequate for the specific external driver's input.
- ⚪ **U16 unused receiver channels 3&4** inputs left floating — tie to a
  defined level to avoid output oscillation (minor).
- ⚪ **NRST** has pull-up (R89 1.5k) + steering diodes but no 100nF to GND —
  ST-recommended but optional given internal filter.
- ⚪ **Designators:** U6 (inductor) and U3 (PPTC fuse) use "U"; conventionally
  L / F. Cosmetic (BOM/silkscreen clarity).

**✅ Confirmed correct:** R32 wired as a 2-terminal rheostat (pins 2+3
shorted, fail-safe against a worn wiper); input caps 2×10µF+220nF/50V;
output caps 4×22µF/25V; CBOOT 100nF BOOT–SW; CVCC 1µF VCC–GND; EN tied to
VIN; inductor (designated **U6** — cosmetic, consider renaming to
L-prefix) correctly bridges SW→5V; downstream AMS1117-3.3 (U2) correctly
wired off the 5V rail; D3/D2/U3 input-protection front-end (Schottky +
TVS + PPTC fuse) present and appropriately sized — and confirmed to be
input reverse-polarity protection, **not** a freewheeling diode for the
inductor (not needed — LMR33630 is synchronous).

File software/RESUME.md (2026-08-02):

# RESUME — drDRO Software (drdro-software-f4)

> Pick-up doc for a fresh Claude Code session. Current state, what's decided, what's open,
> next steps, commands, gotchas. **Full design is in `docs/migration_design.md`; phased work
> in `docs/migration_todo.md`.** Read those two before touching code.

## What this project is

The host-side successor to **rotary-controller-python (RCP)**: a Kivy DRO / single-axis
controller UI for the **drDRO** STM32F411 board. Mandate for this repo:
1. **Port RCP 1:1** (every screen/feature — Kivy UI unchanged).
2. **Replace the driver layer** — RS-485 **Modbus RTU** (`minimalmodbus`) → the firmware's
   **custom CLI line protocol** (`pyserial`).
3. **Add firmware update + bank management** over the same RS-485 bus (YMODEM).
4. **Move static config to the board's flash settings** instead of re-pushing on every reconnect.

The firmware side (`../drdro-firmware-f4`) is **already shipped & HW-verified** (protocol +
dual-bank IAP bootloader + persistent settings, ≥ v0.2.2). We are building the host that
talks to it.

## Current state (2026-06-29)

- ✅ Repo initialized: uv project, branch `main`, package `dro`, `pyserial`. Design docs +
  decisions confirmed (D2–D6); see `docs/migration_design.md` / `migration_todo.md`.
- ✅ **Firmware Phase 0b (HW-verified):** `sta` extended with `servo.tgt`+`servo.mode` on branch
  `feat/sta-servo-fields` in `../drdro-firmware-f4` (commit `0a1e6b3`). **Flashed to the board.**
  ⚑ Not yet merged to firmware `main`/`dev`.
- ✅ **Phase 1 (HW-verified):** `dro/comms/protocol_client.py` — async, lock-guarded line-protocol
  client (framed req/resp, CRC verify, glitch retry, `*HH`). 15 unit tests.
- ✅ **Phase 2 + 3 (HW-verified):** dispatchers re-pointed to the protocol —
  `board.py` (poll loop + sync↔async bridge + `map_sta` + settings cache + debounced save),
  `servo/axis/input/els`, plus ported `ctype_calc/saving_dispatcher/formats/axis_transform`.
  Firmware = source of truth for `servo.max/acc/jog` (read on connect); ratios pushed live,
  never saved. 4 unit tests + a headless HW harness drove the live board successfully.
- ✅ **Phase 4 (built & rendering):** full Kivy UI ported into `dro/` (19 screens + 51 `.kv`,
  home modes/bars, popups, widgets, plot, toolbars) + app shell (`app.py`/`main.py`/`manager.py`/
  `appsettings.py`/`feeds.py`) + pattern dispatchers + assets. App builds headless (Xvfb+SDL2/GL),
  all 19 screens instantiate, the home screen renders live against the board (v0.1.0).
- ✅ **Phase 4 interactive parity (real desktop, DISPLAY :0):** all 24 screens toured + render,
  4 home modes, keypad; servo values read live from flash. Fixed a servo-mode oscillation bug
  (async write reverted by laggy `sta` read) — `_expected_mode` guard (commit e1a1dc5).
- ✅ **Live motion (HW-verified via UI):** servo jog ramps pos; index counts `stepsToGo`→0 and
  completes. Confirmed firmware motion is solid via a direct-client probe too.
- ✅ **Phase 5 (HW-verified):** `dro/comms/ymodem.py` + `updater.py` (GitHub release list/download +
  dual-bank flash flow) + `ProtocolClient.run_blocking` + `Board.pause/resume`; firmware screen
  (version, active bank, boot-bank selector, manual reset, GitHub version list, install, progress
  bar, status log). Flashed a local `.bin` into the inactive bank over RS-485 and booted it
  (bank 1→0, version updated). **GitHub fetch path untested here (no network/CA certs).**
- ✅ **Encoder filter + machine profiles (2026-07-02, not yet HW-verified):**
  - `scales.filt` (firmware `scale_filter[4]`, 0–15, default 5) wired end-to-end: new
    `FilterItem` widget on the per-input screen (keypad + −/+ steppers + live reject-time/
    max-frequency info line, `dro/utils/encoder_filter.py`), board-persisted via
    `write_persisted`, synced on connect (`InputDispatcher.filterValue`); help
    `dro/help/encoder_filter.rst` has the full 0–15 table @100 MHz.
  - **Machine profiles** (`dro/profiles.py` + Profiles setup screen): YAML files under
    `~/.config/drdro-software/profiles/` with metadata (name/created/sw+fw versions), the
    board-persisted vars, and the machine host YAMLs (Axis/CoordBar/ServoBar/Els — formats/
    network stay device-local). Apply = auto timestamped backup → rewrite host files → push+
    save board section → `os.execv` app restart.
  - **Firmware update backup/restore:** `firmware_screen._install` snapshots the board vars,
    writes a timestamped backup profile pre-flash, and after reboot auto-restores (diff-only,
    single save) anything a settings-layout change wiped. 13 new unit tests (36 total green).
- ✅ **Firmware-compat check + home update banner (2026-07-02, HW-verified):**
  `dro/utils/fw_compat.py` declares `COMPANION_FW_VERSION` (v0.6.0 — needs `scales.filt`);
  `Board` compares the connected firmware on (re)connect (`firmware_update_required`
  property) and the home page shows a full-width tap-to-update banner
  (`dro/components/home/fw_update_banner.py`) → `goto("firmware")`. Bump the constant
  whenever the software starts using a newer protocol var. Verified live: bench board at
  v0.5.1 raised the banner by itself; tap landed on the firmware screen; the GitHub release
  fetch worked from this machine (v0.6.0 listed — the "fetch untested" caveat below is now
  cleared). 9 new unit tests (45 total green). OTA v0.5.1→v0.6.0 not yet performed.
- ✅ **Software-update screen de-RCP'd (2026-07-02, verified live fetch):** update_screen now
  points at THIS repo (`bartei/drdro-software-f4`), installs into the drdro-arch appliance
  layout (`/opt/drdro/app` + its `.venv/bin/pip`; was `/rotary-controller-python` + bare pip),
  verifies TLS via certifi (same as updater.py), and with "experimental" ON also lists beta
  prerelease tags (vX.Y.Z-beta.N — installable via `git checkout tags/…`) ahead of the dev
  entry. Also moved ProfilingPanel dumps to `~/.config/drdro-software/profiling/` (old RCP
  config dir; `profiles/` is machine profiles). Headless run confirmed the real release list
  (v1.3.0…v1.0.0) renders and the install button disables on the current version.
- ⏳ **Next: Phase 6 (release & polish)** — CI (GitHub Actions build+tests, semantic-release),
  verify GitHub firmware fetch on a networked machine, RCP dead-code cleanup, Modbus→protocol
  user notes. Optional: expose rollback/erase/crc in the firmware UI (plumbing exists).
  Bench-verify the encoder filter (`scales.filt`) + profile apply/restart on the Pi.

### Running the UI
- `uv run python -m dro.main` (config: `config.ini` at repo root; serial port set there).
- The board poll loop is **asyncio** (not Kivy Clock); `MainApp.build` calls `board.start()` after
  the loop is up (under `async_run`). `board._spawn` schedules writes on that loop.
- **NixOS headless GL recipe** (Xvfb): the uv-wheel SDL2 needs system GL/X libs on `LD_LIBRARY_PATH`.
  Find real `.so` dirs (NOT `-dev` outputs) for `libGL.so.1` (libglvnd) + `libX11/Xext/Xrender/
  Xcursor/Xi/Xrandr/Xinerama`, then:
  `nix-shell -p xvfb-run mesa --run "xvfb-run -a -s '-screen 0 1024x600x24' env LD_LIBRARY_PATH=<dirs> LIBGL_ALWAYS_SOFTWARE=1 uv run python -m dro.main"`.
  On a real desktop with system GL this is unnecessary — just `DISPLAY=:0 uv run python -m dro.main`.
  Scratchpad has `run_app.py` (screenshot-then-quit) + `gldirs.txt` (the resolved lib dirs).
- ST-Link flashing leaves the board in ST ROM (HW-1 floating BOOT0). Recover with an openocd
  `reset run` (`-f interface/stlink.cfg -f target/stm32f4x.cfg -c "init; reset run; exit"`).
- Host config dir is `~/.config/drdro-software` (was `rotary-controller-python`). No Modbus address.

## Source repos (read-only references)

- `../rotary-controller-python` — the app being ported. Driver layer to replace:
  `rcp/utils/{communication,base_device,devices,ctype_calc}.py`. State in
  `rcp/dispatchers/{board,axis,input,servo,els,formats,...}.py`. UI in `rcp/components/**`.
  `rcp/CLAUDE.md` holds the coding standards (carried over). `rcp/todo.md` lists open items —
  note *"STM32 firmware flashing from Pi"* is this project's Part E.
- `../drdro-firmware-f4` — the firmware. **Protocol truth:**
  `docs/protocol_design.md`, `docs/dualbank_design.md`, `shared/Settings.h`,
  `shared/Bootloader.h`, and the working host updater **`tools/dro_update.py`** (port its
  framed-CLI reader + YMODEM sender). `app/test/test_protocol/` has exact wire-format tests.
- `../rcp-v2` — a *separate* NiceGUI/web experiment. **Not in scope**; ignore.

## Authoritative protocol facts (verified from firmware source, not just the design doc)

**Wire format:** single device, no addressing, 115200, RS-485 auto-direction (host does
nothing for direction). Request `cmd [args] [*HH]\n` (`*HH` = optional uppercase-hex XOR-8,
validated if present). Response: `key=value\n` body lines, then `crc=HH\n` (XOR-8 of body),
then a **blank line** terminator. `error=<reason>` line ⇒ failure. Arrays = one comma-joined
line. A lone `\n` repeats the last command.

**App commands:** `sta set get settings save load bank rollback version help update reset`.
**`sta` returns ONLY:** `scales.pos`, `scales.speed`, `servo.pos`, `servo.speed`.

**Variable registry (real names → firmware fields):**
| var | type | n | RW | field |
|---|---|---|---|---|
| `scales.pos` | i32 | 4 | RW | `scales[i].position` |
| `scales.speed` | i32 | 4 | RO | `scales[i].speed` |
| `scales.num` | i32 | 4 | RW | `scales[i].syncRatioNum` |
| `scales.den` | i32 | 4 | RW | `scales[i].syncRatioDen` |
| `scales.sync` | u16 | 4 | RW | `scales[i].syncEnable` |
| `servo.max` | f32 | 1 | RW | `servo.maxSpeed` |
| `servo.acc` | f32 | 1 | RW | `servo.acceleration` |
| `servo.jog` | f32 | 1 | RW | `servo.jogSpeed` |
| `servo.mode` | u16 | 1 | RW | `fastData.servoMode` (0=off,1=sync/index,2=jog) |
| `servo.pos` | u32 | 1 | RO | `servo.currentSteps` |
| `servo.speed` | f32 | 1 | RO | `servo.currentSpeed` |
| `servo.tgt` | i32 | 1 | RW | `servo.stepsToGo` (write = start indexed move) |
| `diag.cycles` | u32 | 1 | RO | `fastData.cycles` |
| `diag.interval` | u32 | 1 | RO | `fastData.executionInterval` |

**RCP→protocol naming:** `servoEnable` (already 0/1/2) → `servo.mode`; servo `direction` →
`servo.tgt`. `ctype_calc.uint32_subtract_to_int32` is **kept** (unsigned encoder deltas).

**Bootloader CLI (firmware-update path):** greeting `bootloader=ready`; commands
`version info bank boot.mode flash erase crc copy rollback boot reset help`. Update flow:
app `update` → `bootloader=ready` → `info` (pick inactive bank) → `flash <bank>` (YMODEM:
STX 1024B blocks, CRC-16 poly 0x1021, EOT handshake) → `bank <bank>` → `boot`. All of this is
already implemented host-side in `../drdro-firmware-f4/tools/dro_update.py` — lift it.

**Board flash settings payload** (`shared/Settings.h`, the ONLY persisted fields):
`scale_num[4] scale_den[4] scale_sync[4] servo_max servo_acc servo_jog servo_mode`
(+ board-control fields the host doesn't own). Ping-pong A/B sectors, magic+CRC32, power-fail
safe, motion-safe `save`.

## Decisions — CONFIRMED (2026-06-29)

- **D2 — Fast poll:** **extend firmware `sta`** to also emit `servo.tgt` + `servo.mode`, so the
  30 Hz loop is a single round-trip. ⚑ **Cross-repo prerequisite** in `drdro-firmware-f4` (one
  extra `respKV` pair + native test) — must land before Phase 2's fast loop is final.
- **D3 — Bus serialization:** **`asyncio`, lock-guarded command queue** in `ProtocolClient`.
  Never blocks the Kivy loop (Kivy already runs under asyncio via `async_run`). `sta` benches
  >100 Hz → headroom to interleave `set`/`get`/`save` between polls.
- **D4 — Dynamic ratios stay in Python:** `scales.num/den` are unit-dependent, frequently
  changing ratio math → Python owns them, `set`s live on connect/change, **never `save`s** to
  flash. (So ratios *are* re-pushed on connect — intentional.)
- **D5/D6 — Persisted settings, firmware = source of truth:** `servo.max/acc/jog` live on the
  board. On connect **READ** them and sync Python (no push, replaces today's `on_connected`
  push); on UI change `set`+`save` (debounced). `scales.sync`/`servo.mode` are read-on-connect
  live state, set on change, not saved.

## Open / deferred decisions

- **D1** package name: `dro` applied in scaffold (vs keep `rcp` to zero-diff). Confirm if you'd
  rather keep `rcp`. *(default: `dro`)*
- **D7** firmware-update `.bin` source + whether to keep RCP's git/pip self-update screen:
  **deferred to Phase 5** — get the protocol working first. *(leaning: local file + GitHub; keep both)*

## Next steps (Phase 1)

1. (Optional) confirm D1; apply `rcp.` → `dro.` rename convention.
2. ⚑ Land the firmware `sta` extension in `drdro-firmware-f4` (Phase 0b) — coordinate before
   finalizing the Phase 2 fast loop.
3. Build `dro/comms/protocol_client.py`: **asyncio lock-guarded command queue**, framed
   request/response, crc verify, turnaround-glitch retry — port from `tools/dro_update.py`.
   (YMODEM `ymodem.py` + `updater.py` come in Phase 5.)
4. Re-point `dispatchers/board.py` + servo/axis/input to the protocol (mapping table §C.3).
5. Settings: **read** board on connect & sync Python (no push); `set`+`save` on UI change;
   ratios `set` live (never saved). Then the UI parity port.
6. See `docs/migration_todo.md` for the full Phase 0b–6 checklist.

## Commands

```bash
uv sync                       # install deps
uv run python -m dro.main     # run the app (once dro/main.py exists)
uv run pytest                 # tests
uv build                      # package
```

NixOS host: tools may not be on PATH — use `nix-shell -p <pkg> --run "<cmd>"` if needed.

## Conventions / gotchas

- **Logging:** `from kivy.logger import Logger; log = Logger.getChild(__name__)`. **Not** loguru.
- snake_case; keep firmware-mirror names where they aid cross-reference; dotted protocol names.
- Branches `main`/`dev`, conventional commits, `python-semantic-release`. **No AI attribution
  in commits/PRs.**
- Single half-duplex bus → only one command outstanding at a time; firmware-update mode takes
  exclusive port ownership (pause `sta`).
- RS-485 turnaround: first TX byte after a long RX can drop — read the full framed response and
  retry glitched commands (the updater already does this).

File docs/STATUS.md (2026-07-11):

# drDRO mainboard — status & resume point

**Last reviewed:** 2026-07-11 · **final pre-order review** — netlist
`Netlist_Schematic1_2026-07-10.net` (**189 comp / 138 nets, zero dangling, all
rails/EP resolved**) + Gerber `Gerber_PCB1_2026-07-11.zip` (4-layer,
JLC04161H-7628 impedance stackup, 100 Ω diff pairs) + project `.epro2`. All three
cross-check as the same current design. (The `.webp` previews inside the `.epro2`
are stale cached thumbnails of an old V1.4/V1.5 mux-era layout — **ignore them**.)
**This file is the authoritative current status.** Per-subsystem detail lives in
the design docs (index at bottom). Most `*_todo.md` files are historical working
notes that this file supersedes — **except `encoder_input_todo.md`, which is the
live tracker for the encoder work** (see OPEN below).

**Δ since 2026-07-04:** the encoder front-end restructure is now **partly done** —
the 3 shared quad receivers became **5 receivers, one AM26LV32E per DB9**
(U7=J1, U8=J2, U9=J3, U10=J4, U11=J5), each A/B only. **Index-Z is still NOT
wired** (DB9 pin 6 free on all 5; spare receiver channels 3/4 tied off; Z GPIOs
unused). SPI NSS pull-up now added (R72). No critical defects found.

## What the board is
5-axis DRO mainboard. STM32F411RET6 (LQFP64) + 5× universal encoder inputs
(differential RS-422 *or* single-ended TTL, no mux) + 3× stepper STEP/DIR/ENA
outputs (via ULN2003) + RS-485 + W5500 SPI Ethernet + 6× opto-isolated inputs
+ 24V→5V (LMR33630 buck) →3.3V (AMS1117) power. Fab: JLCPCB.
Encoder front-end is currently **A/B-only across 3 shared quad receivers**
(U7/U8/U9); the agreed **one-receiver-per-DB9 (5 chips) + index-Z** restructure
is still to be implemented — see OPEN and `encoder_input_todo.md`.

## Subsystem status — all verified against the latest netlist
| Subsystem | Status |
|---|---|
| Power: 24V→5V buck (LMR33630ADDAR) | ✅ FB trim 4.82–5.20V, all rails/EP correct |
| Power: 5V→3.3V (AMS1117) + MCU power | ✅ all 5 VDD/VSS pairs wired, VCAP=2.2µF |
| MCU pin assignment | ✅ encoders on TIM1–5, all peripherals on valid AF pins |
| Reset + BOOT0 circuits | ✅ pull-up + steering diodes + buttons |
| Encoder inputs (universal, no mux) | 🚧 **5-chip-per-DB9 done** (U7=J1…U11=J5, AM26LV32EIDR, 2.2k bias, no term, receivers→MCU on TIM1–5); spare recv ch tied off; **index-Z still NOT wired** (DB9 pin6 free, Z GPIOs unused) |
| Motor outputs (3× STEP/DIR/ENA) | ✅ PC0–3/PC10–12→ULN2003→CN6/CN7, M3_DIR off PC13 |
| RS-485 (GPIO-DE) | ✅ PA11 DE, 680Ω bias, 120Ω term — 10Mbps-ready. **U5 = SP3485EN-L/TR (C8963, SOIC-8) now PLACED** in Gerber 2026-07-11 (pinout verified: RO→UART_RX, RE̅+DE→UART_DE, DI→UART_TX, A/B, VCC=3V3). SOIC-8 has no EP → old "EP→GND" item moot |
| W5500 Ethernet | ✅ SPI/bias/PMODE/magnetics/LEDs/crystal all correct |
| Analog outputs (2× 0–10 V, VFD ref) | ✅ **in netlist + reviewed 2026-07-10** — U20 GP8403 dual I²C DAC, VCC=VIN(24 V), EP→GND, on shared I²C1 (PB8/PB9, addr 0x58); VOUT0/1→AO0/AO1 (1 µF + SMAJ12A + 47 Ω)→CN9; 4–20 mA dropped. See `analog_output_design.md` |

## OPEN — before fab (schematic/wiring)
- [x] 🆕 **2× 0–10 V analog outputs (VFD speed ref) — DONE in netlist + reviewed
      2026-07-10.** U20 **GP8403** dual 12-bit I²C DAC (**C3152007**), VCC=VIN(24 V),
      EP→GND, on the **shared I²C1** bus (PB8/PB9, **addr 0x58**), pull-ups R14/R74
      reused. VOUT0→AO0 / VOUT1→AO1, each 1 µF + SMAJ12A TVS (C113957) + 47 Ω → CN9
      (AO0/AO1/GND/GND). 0–10 V only — 4–20 mA dropped. Caps 1 µF per official
      datasheet. Detail: `analog_output_design.md` / `analog_output_todo.md`.
      Open (optional): local 0.1 µF + RC on VCC (24 V-bus noise); reserve I²C 0x58.
- [x] **Encoder split → one AM26LV32E per DB9 (5 chips).** DONE in
      `Netlist_PCB1_2026-07-09.net`: U7=J1, U8=J2, U9=J3, U10=J4, U11=J5, each
      A/B, per-line 2.2k pull-up + 2.2k/2.2k bias, receivers enabled (pin4=3V3),
      spare ch3/4 inputs tied to defined levels, outputs on TIM1–5. Verified.
- [x] ~~Index-Z~~ **DESCOPED** (user decision 2026-07-09): Z inputs will never be
      connected. DB9 pin 6 stays free; spare receiver channels remain tied off. No
      work owed. Encoder front-end is final at 5×AM26LV32E, A/B only.
- [x] ~~CN1~~ NON-ISSUE (user 2026-07-09): CN1 is the pluggable **mating plug**
      carried in the BOM for the WJ15EDG headers — intentionally unwired. Ignore.
- [x] **I²C expansion bus pull-ups** added (R14/R74 = 4.7k to 3V3 on SDA/SCL).
      DONE. Optional still: ESD footprints on the DB9-routed SCL/SDA if long cables.
- [x] **Optos — OK as designed** (decision 2026-07-09): TLP2309s wired correctly;
      keep board-5V sinking inputs. Moving to an isolated field domain later is just
      a pin swap (LED-anode resistor → field supply), so no rework now.
- [ ] **Add ESD/surge protection on IN1–6** (requested): per line at CN4/CN5,
      bidirectional TVS to GND = **SMAJ6.0CA (JLCPCB C466511)**, 6V standoff (clears
      the 0–5V operating range); optional ~100Ω series R to the opto for extra LED
      protection.
- [ ] 🔧 **Replace D1 TVS** → **SMCJ30A (JLCPCB C408374 or C135160)**, unidirectional,
      30V standoff, SMC/DO-214AB (same footprint as D1). Clamps earlier (starts ~33V)
      and lower than the old SMDJ36CA so it actually protects the LMR33630
      (VC ~35–40V at realistic surge currents, < the 42V abs-max). D2 (SL10100) fine.
- [x] **SPI NSS pull-up**: ~10k on W5500 SCSn→3V3 now present (R72). DONE.
- [ ] **RESET**: optional 100nF to GND (ST-recommended, not required).
- [ ] **W5500 crystal**: optional 1MΩ feedback (XI–XO) + 0Ω series on XO per
      WIZnet ref Fig 3 (usually not needed — internal feedback exists).
- [ ] **Connector grouping** (optional): motor 2 is split across CN6 (M2_STEP)
      and CN7 (M2_DIR). Regroup per-motor if desired. CN6/CN7 are signal-only.

## PCB LAYOUT — FINAL pre-order review 2026-07-11 (`Gerber_PCB1_2026-07-11.zip`)
Reviewed from Gerber + drill + flying-probe + `.epru` (no raw-Gerber renderer here;
the `.epro2` `.webp` previews are stale — old mux-era layout, ignored).
- [x] **Layer set complete** for fab: 2 outer + **2 inner copper (Inner1/Inner2)**,
      both masks/silks, **top paste only → all SMD top-side** (no bottom SMD — confirm
      intended), board-outline, 3 drill files, flying-probe. Board **178.05×75.69 mm**.
- [x] **Impedance stackup SET = `JLC04161H-7628`** (JLCPCB 4-layer, 1.6 mm; L1→L2
      = 0.2104 mm 7628 prepreg). **Ethernet diff pairs present at W=0.2 mm** (8 mil) →
      100 Ω differential; TXP/TXN & RXP/RXN run ~10–12 mm U19→magjack J6 on top. GOOD.
- [x] **U20 GP8403 analog + CN9** placed top; EP→GND; nets per netlist. GOOD.
- [x] **U5 SP3485EN SOIC-8** placed (RS485), pinout verified. GOOD.
- [x] **Fab limits OK for JLCPCB**: min via drill **0.305 mm** (≥0.3 std), min trace
      **0.203 mm / 8 mil** (≫3.5 mil min), 1033 vias, standard hole sizes. 2× 3.3 mm
      NPTH mounting holes (a 178 mm board often wants 4 — confirm mechanical intent).
- [ ] 🛒 **ORDER-TIME CHECKLIST (JLCPCB):** (1) **4-layer**, 1.6 mm; (2) **Impedance
      Control = YES**, stackup **JLC04161H-7628**; (3) confirm Inner1(L2) is solid GND,
      unbroken under the U19→J6 pairs; (4) pairs stay top-layer, intra-pair length
      matched (raw pad offset ~2.3–2.7 mm — fine for 100BASE-TX). Project renamed to
      **"V1.5 Final"** (matches silk); still confirm 4-layer at order.
- [x] **Final routing pass re-verified 2026-07-11** (Gerber 01:50, `.epro2` V1.5
      Final): flying-probe connectivity unchanged vs the reviewed design — all parts
      present, no stray muxes, diff pairs intact, stackup + 0.2 mm pairs retained,
      fab limits unchanged. Copper edit was routing polish only. Netlist connectivity
      unaffected (`Netlist_Schematic1_2026-07-10.net` still current for wiring).

## PCB LAYOUT — reviewed 2026-07-09 (`Gerber_PCB1_2026-07-09.zip`)
4-layer, 178.3×76.0mm. **Inner1 = solid GND plane (unbroken); Inner2 = full plane
too** (confirm its net). 1106 stitching vias + component holes. Reviewed via
rendered layers.
- [x] **Buck U2 EP → GND**: via-stitched thermal array present under U2, plus dense
      GND stitching. GOOD. (SW→L short: U2/U3 adjacent; HF input cap C3 at U2.)
- [x] Encoder receivers U7–U11 placed AT their DB9s (best differential SI). GOOD.
- [x] W5500: decoupling clustered at U19 AVDD pins, X2+load caps close, EXRES/PMODE
      in place, diff pairs routed together to J6. GOOD.
- [x] MCU: clean 45° fan-out, crystal caps (C17/C21) at U6, VCAP C22 near. GOOD.
- [ ] ~~U5 DFN EP → GND~~ — moot once U5 → SP3485EN SOIC-8 (no exposed pad).
- [ ] 🔍 Confirm **Inner2 plane net**; if it's a 2nd GND, verify 5V/3V3/24V trace
      widths on outer layers carry the current (power traces looked adequately wide).
- [ ] Local 100nF per logic IC (14×100nF on board) — verify per-IC coverage;
      TLP2309 datasheet wants a 0.1µF at each opto's Vcc(6)–GND(4).
- [ ] 🔍 Cap voltage/case: CIN C1/C2 = 1206 10µF (design specified 1210/50V);
      COUT C8/C10/C12/C13 = 22µF **0805** (design specified 1210). Confirm
      CIN ≥50V, COUT ≥16–25V; account for DC-bias derating in the smaller cases.
- [ ] 🔍 Verify diode orientation in schematic: D1 (TVS, shunt→GND), D2 (SL10100
      series→VIN, reverse-polarity), D3/D4 (1N5819WS reset steering).
- [ ] MCU crystal X1 (12pF) load caps vs its CL — verify. (W5500 X2 18pF = OK.)
- [ ] Keep buck hot loop tight; FB trace away from SW/inductor; W5500 diff pairs
      length-matched; RJ45 shield/Bob-Smith (HR911105A likely internal — verify).

## FIRMWARE notes
- **SPI NSS**: drive PB12 as **GPIO software CS** (SPI2 SSM=1/SSI=1), *not* HW-NSS —
  W5500 needs SCSn to frame each transaction (VDM mode).
- **Encoders**: ENC5 must use **TIM5 (AF2)**, not TIM2 (PA0/PA1 are both).
- **RS-485**: assert PA11 (DE) before TX, deassert in USART **TC** interrupt
  (F411 has no hardware DEM). USART1 on APB2 → 10Mbps clean.
- **ISO_IN1–6**: enable STM32 internal pull-ups (TLP2309 open-collector outputs).
- **Motor STEP**: no free timer channels (TIM1–5 = encoders) → GPIO/DMA step gen.

## BRING-UP checklist
- [ ] 5V rail correct across 0–2A load; efficiency/thermal at 2A.
- [ ] 3.3V rail; MCU boots; SWD connects.
- [ ] Each encoder counts (differential + single-ended scale).
- [ ] RS-485 loopback at target baud; W5500 link + ping; each motor STEP/DIR.

## Document index
- `STATUS.md` — this file (authoritative current state).
- `mcu_pinmap.md` — full verified STM32F411 pin map + AF audit.
- `power_supply_design.md` — buck + RS-485 detail, decisions, equations, review rounds.
- `encoder_input_design.md` — universal encoder front-end design + rationale.
- `board_review_todo.md` — full-board review findings (re-verified vs current export).
- `encoder_input_todo.md` — **live** phased tracker for the pending encoder restructure.
- `power_supply_todo.md` — historical working notes (power stage complete).

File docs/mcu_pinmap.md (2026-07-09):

# STM32F411RET6 (LQFP-64) pin map — verified 2026-07-04

Full pin-function audit against ST datasheet Table 8 (DocID026289). U6 = MCU.
Re-verified against `Netlist_PCB1_2026-07-09.net` (177 comp / 133 nets): all 53
used MCU pins on valid functions, 11 GPIOs free (PC13/14/15, PA2/3/4, PC8/9, PD2,
PB4/5), no shorts.

## Power — all 5 VDD/VSS pairs wired ✓ (was the critical finding, now FIXED)
An earlier export left pins 18 (VSS) / 19 (VDD) unconnected; the current netlist
wires both. Verified:
| VSS | 12(VSSA)✓ 18✓ 31✓ 47✓ 63✓ |
| VDD | 13(VDDA)✓ 19✓ 32✓ 48✓ 64✓ |
VBAT(1)→3V3 ✓, VCAP_1(30)→2.2µF (C22) ✓.

## Encoders — hardware quadrature (TIM CHx), all verified ✓
| Enc | A / B | pins | Timer |
|---|---|---|---|
| ENC1 | PA8/PA9 | 41/42 | TIM1 CH1/CH2 (AF1) |
| ENC2 | PA5/PB3 | 21/55 | TIM2 CH1/CH2 (AF1) |
| ENC3 | PA6/PA7 | 22/23 | TIM3 CH1/CH2 (AF2) |
| ENC4 | PB6/PB7 | 58/59 | TIM4 CH1/CH2 (AF2) |
| ENC5 | PA0/PA1 | 14/15 | TIM5 CH1/CH2 (AF2) |
All 5 on distinct timers, valid CH1/CH2 pairs. FW: ENC5 must use TIM5 (AF2)
not TIM2 (PA0/PA1 are also TIM2 CH1/CH2, but TIM2 = ENC2). Receiver outputs
(AM26LV32EIDR, 3.3V) go direct to MCU — safe for PA0 (TC/3.3V-only).
As built (2026-07-09) the A/B pairs come off **5 quad receivers, one per DB9**
(U7=J1/ENC1 … U11=J5/ENC5). The still-pending **index-Z** work will add 5 Z
inputs — land them on the free GPIOs listed below (Z is a plain input); a spare
channel of each receiver is available to buffer a differential Z.

## Comms
- USART1: PA15 TX (50, AF7), PA10 RX (43, AF7), PA11 DE (44, GPIO) ✓
- I2C1: PB8 SCL (61, AF4), PB9 SDA (62, AF4) ✓ — NO external pull-ups yet (expansion bus)
- SPI2: PB12 NSS / PB13 SCK / PB14 MISO / PB15 MOSI (33-36, AF5) ✓ — **wired to
  W5500** (SCSn/SCLK/MISO/MOSI); INTn→PC6 (37), RSTn→PC7 (38), both pulled up
- SWD: PA13 SWDIO (46), PA14 SWCLK (49) ✓

## Motor (GPIO → ULN2003 U16 → CN6/CN7)
| Sig | pin | note |
|---|---|---|
| M_ENA | PC10 (51) | ✓ shared enable |
| M1_STEP/DIR | PC12/PC11 (53/52) | ✓ |
| M2_STEP/DIR | PC0/PC1 (8/9) | ✓ (was PD2/PB4) |
| M3_STEP/DIR | PC2/PC3 (10/11) | ✓ M3_DIR moved off PC13 → PC3 |
All 7 channels MCU→ULN2003 (U16)→CN6/CN7 verified. STEP pins not on free timer
channels (TIM1-5 used by encoders) → step gen is GPIO/DMA, not HW PWM. ULN2003
slow (~1µs).

## Other I/O
- ISO_IN1-6: PC4,PC5,PB0,PB1,PB2,PB10 (24-29) GPIO in ✓
- Status LED: PA12 (45) → LED3 ✓
- Reset: NRST(7); R10 1.5k pull-up→3V3, D3 SWD-steer, D4 button-steer ✓ (no 100nF cap - optional)
- BOOT0(60): R12 1.5k pull-down→GND, BOOT1 button→3V3 ✓
- Crystal: PH0/PH1 (5/6) ✓

## Free GPIOs (spare) — 11 pins, verified from netlist
PC13 (2), PC14 (3), PC15 (4), PA2 (16), PA3 (17), PA4 (20), PC8 (39), PC9 (40),
PD2 (54), PB4 (56, NJTRST), PB5 (57). (PC0–3 now motors; PC6/PC7 now W5500
INT/RST.) This pool covers the 5 index-Z inputs for the pending encoder
restructure. Avoid PC13 where drive current is needed (backup-domain pin: ≤3mA,
no current source) — fine as a plain input.

## JTAG note
SWD-only: PA15=JTDI→USART1_TX and PB3=JTDO/SWO→ENC2B are repurposed. PB4=NJTRST
is now FREE (M2_DIR moved to PC1). Fine — lose JTAG + SWO trace, keep SWD.

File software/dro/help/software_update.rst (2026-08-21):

Update
======

Keeps the DRO up to date. One button updates everything.

The software running on this screen and the firmware running on the
board are released together and always carry the **same version
number**. Updating brings both to the same release, so the two halves
can never drift apart.

Fields
------

Installed Version
^^^^^^^^^^^^^^^^^
The version currently running. Read-only.

Available Version
^^^^^^^^^^^^^^^^^
The newest release published online. Checked automatically whenever
you open this page; tap it to check again. Requires an internet
connection.

Update
^^^^^^
Downloads and installs the release shown above — software **and**
firmware — then restarts. The button is disabled when you are already
up to date.

What happens when you press Update
----------------------------------

1. Both the software and the firmware are downloaded and checked for
   corruption.
2. The firmware image is saved to the DRO's own storage.
3. The new software is installed.
4. The DRO restarts.
5. On the way back up, the board is updated from the saved firmware
   image. This step needs no internet connection.

Nothing is installed until **both** downloads have finished and passed
their integrity check, so losing the network partway through leaves the
DRO exactly as it was.

Version mismatch warning
------------------------

If the board's firmware version does not match the installed software
version, an orange banner appears on the home screen. Tap it to come
here and update. The warning appears whether the board is older *or*
newer than the software — both mean the two halves are out of step.

This can happen if a board is swapped in from another machine, or if a
previous update was interrupted. Running the update resolves it.

Notes
-----

- An internet connection is needed to download an update, but not to
  finish applying one after the restart.
- If the board update does not complete, it is retried automatically
  the next time the DRO starts. The board keeps a working copy of its
  previous firmware and stays usable in the meantime.
- **Advanced…** opens firmware bank selection, manual flashing and the
  activity log. Those are diagnostic and recovery tools — the normal
  update path never needs them.

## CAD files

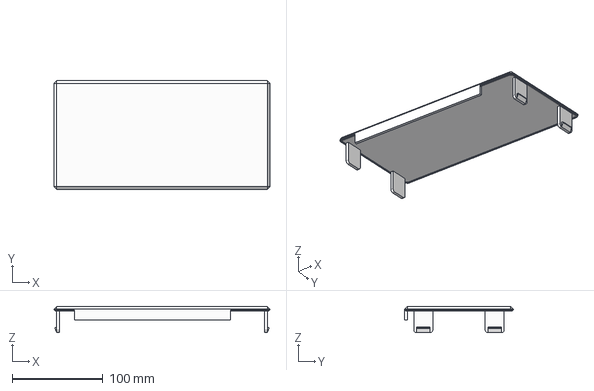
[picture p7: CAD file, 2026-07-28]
enclosure/top-cover.step
238.0 x 119.7 x 29.0 mm

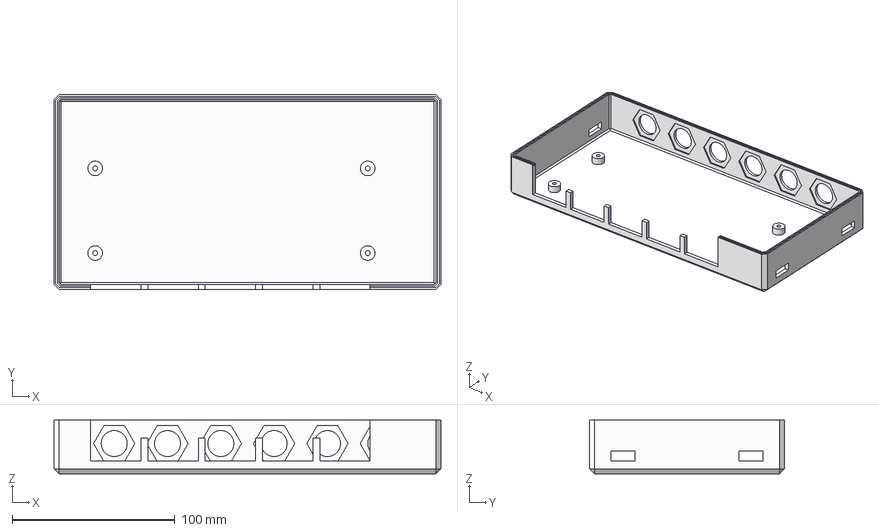
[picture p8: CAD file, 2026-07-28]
enclosure/bottom-shell.step
238.0 x 119.7 x 33.0 mm

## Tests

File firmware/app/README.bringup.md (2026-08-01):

# drDRO mainboard V1.5 — firmware

Firmware for the **STM32F411RET6** on the DRDRO Mainboard V1.5 (the board in this
repo). Built with PlatformIO + STM32Cube HAL + FreeRTOS.

The tested/working firmware for the *previous* board lives in the sibling project
`../../drdro-firmware-f4` and is the baseline this project was started from. That
project targets a **different MCU and pin map** — see "Deltas from the baseline".

## Current scope: Ethernet bring-up — ✅ VERIFIED ON HARDWARE

This image is deliberately minimal. It exists to prove the two things that must
work before anything else is worth porting:

1. the MCU boots and runs at the right clock (blinking status LED), and
2. the **W5500 Ethernet controller comes up and obtains an address via DHCP**.

Both confirmed on the first board (2026-07-31): 100 MHz from the 16 MHz crystal,
SPI2 reads *and* writes to the W5500 verified, DHCP lease obtained, and the board
answers ICMP from another host on the LAN (~1.2 ms). See the 10 Mbps caveat below.

The motion stack (encoders, step generation), the RS-485 line protocol, the
GP8403 analog outputs, the opto-isolated inputs and the IAP bootloader from the
baseline are **not ported yet**.

## Build / flash

PlatformIO Core is required (`pip install platformio`).

```sh
pio run                 # build
pio run -t upload       # flash over ST-Link (SWD)
pio run -t clean
```

Artifacts land in `.pio/build/drdro_mainboard_v15/firmware.{elf,bin,hex}`.

Debug output goes out the **RS-485 port at 115200 8N1** (USART1, DE on PA11) and
reports the MAC, link transitions and the DHCP-assigned address:

```
drDRO mainboard V1.5 (STM32F411RET6) <git describe>
SYSCLK 100000000 Hz
W5500: ready, MAC 02:xx:xx:xx:xx:xx
ETH: link up
DHCP: discovering...
DHCP assigned: IP 192.168.1.42/255.255.255.0 GW 192.168.1.1 DNS 192.168.1.1
```

## ⚠ Ethernet: this W5500 only works at 10 Mbps

**Verified on hardware 2026-07-31.** The board obtains a DHCP lease and answers
ping only when the PHY is forced to **10BASE-T**. At 100BASE-TX the link comes up
normally but **not one frame is ever received**.

Measured with a MACRAW sniff (receives every frame on the wire, no MAC filter),
same board, same cable, same switch — only the PHY speed differed:

| PHY mode | link | bytes received in 4 s |
|---|---|---|
| **10M half** | up | **1726** |
| auto-neg (settles at 100M) | up | **0** |
| 100M full | up | **0** |
| 100M half | up | **0** |
| **10M full** | up | **1950** |

`Sn_RX_RSR` only counts CRC-good frames, so a PHY that cannot decode 100BASE-TX
yields exactly zero rather than "some errors" — which is why this looked at first
like "no DHCP server on the network".

Consequences:

- `src/Net.c` tries **10M half first** and stays there once DHCP succeeds.
- **A 10 Mbps-capable switch is required.** Many modern gigabit switches have no
  10BASE-T support at all; with such a switch both 10M modes fail to link and
  there is no working configuration. That was the original bring-up failure.
- This is **not** a fault of this PCB: a broken RXP/RXN pair or bad magnetics
  would fail at 10 Mbps too. The same behaviour was previously seen on unrelated
  W5500 breakout boards.
- Set `-D NET_SELFTEST=1` to re-run the per-mode measurement on new hardware
  (adds ~40 s to boot). Raw W5500 registers are mirrored into the `netDiag`
  struct for inspection over SWD.

## Status LED (LED3, PA12)

LED3 is wired **active low** (cathode to PA12, anode via R13 to 3V3). One LED has
to carry the whole bring-up state, so each state has its own pattern:

| Pattern (on/off ms) | Meaning |
|---|---|
| 500 / 500 — even 1 Hz blink | booting, W5500 not up yet |
| 800 / 200 — mostly on | **W5500 not responding** (VERSIONR != 0x04): check SPI2 / CS |
| 100 / 100 — fast flicker | chip alive, **Ethernet link down** (cable/switch) |
| 100 / 400 — short pulses | link up, DHCP in progress |
| 100 / 900 — one blip per second | DHCP failed, backing off before retry |
| 50 / 1950 — one brief flash every 2 s | **address leased — healthy** |

## Deltas from the `drdro-firmware-f4` baseline

These are the changes that were required for this board. Pin assignments come
from the board netlist (`Netlist_Schematic1_2026-07-10.net`), cross-checked
against `../docs/mcu_pinmap.md` — **not** from the baseline project.

| | baseline (`drdro-firmware-f4`) | this project |
|---|---|---|
| MCU | STM32F411CEU6, LQFP-48 | **STM32F411RET6, LQFP-64** (`genericSTM32F411RE`) |
| HSE crystal | 8 MHz | **16 MHz** (X1 = X322516MLB4SI) |
| PLLM | 4 | **8** (keeps SYSCLK at 100 MHz) |
| Status LED | PB12 | **PA12**, active low |
| Link script | app @ `0x08020000` (IAP) | framework default @ `0x08000000` |
| Ethernet | none | **W5500 on SPI2** + DHCP |

The crystal change is the subtle one: PB12 on this board is the W5500 chip
select, and leaving `PLLM = 4` with a 16 MHz crystal would request a 200 MHz
SYSCLK. `src/main.c` carries `_Static_assert`s over the whole clock tree so a
wrong `HSE_VALUE` or PLL divider is a **build error**, not a silent bring-up
failure.

## Layout

```
platformio.ini            build config; HSE_VALUE and the ioLibrary chip select
include/BoardPins.h       authoritative V1.5 pin map (single source of truth)
include/Net.h             W5500/DHCP bring-up API
src/main.c                clock tree (+ compile-time checks), blink task
src/Net.c                 SPI glue for the ioLibrary, W5500 reset, DHCP task
src/spi.c                 SPI2 master, software CS (W5500 needs VDM framing)
src/usart.c               USART1 + RS-485 DE, blocking debug print
src/gpio.c                LED + W5500 nRST/nINT/CS
lib/FreeRTOS/             vendored, unchanged from the baseline
lib/ioLibrary/            vendored WIZnet driver subset (W5500 + DHCP)
support/                  hard-float, git version stamp, .hex emit
```

### Notes carried over from the hardware review

- **SCSn must be a software GPIO** (PB12), not hardware NSS: the W5500 frames a
  whole variable-data-mode transaction with SCSn. See `../docs/STATUS.md`.
- **RS-485 DE** is a plain GPIO — the F411 has no hardware driver-enable, so DE is
  asserted before TX and released once TC is set.
- When the encoders are ported: **ENC5 must use TIM5 (AF2)**, not TIM2 — PA0/PA1
  are valid for both, but TIM2 belongs to ENC2.
- When the inputs are ported: enable **internal pull-ups** on ISO_IN1–6, the
  TLP2309 outputs are open-collector.

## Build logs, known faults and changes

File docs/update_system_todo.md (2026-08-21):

# Update System — Monorepo Release & Single-Step Update

> Phased tracker for consolidating software + firmware releases onto a **single version
> tag** published from this monorepo, and collapsing the two-page developer update flow
> into a **one-button user operation**. Mirrors the repo convention (design context inline;
> one-liner checkboxes per phase).
>
> Status: **implemented, unreleased** (2026-08-02). Phases 1–6 done with 100% test
> coverage on the new modules (270 tests green). Phase 7 is cross-repo (`drdro-arch`)
> and Phase 8 needs a real release plus hardware — both still open. Items marked ⚑
> could not be proven from this repo.
>
> **Released for validation:** `v1.3.0-beta.1` / `v1.3.0-beta.2` on `dev`. Remaining
> open items all need physical hardware or a stable-tag decision.

---

## Goals

1. **One version for the whole stack.** A single semantic-release tag on `bartei/drdro-mainboard`
   versions firmware *and* software. No independent version streams.
2. **GitHub releases are the single source of truth.** Every artifact the appliance needs is a
   named asset on the release for that tag.
3. **Single-step update.** The user picks a version and presses one button; software and
   firmware are both brought to that version. No separate firmware page visit, no ordering
   for the user to get right.
4. **Coherence by construction.** If the board's firmware version differs from the installed
   software version, the UI raises a warning and requests an immediate update to realign.
5. **A user-facing update page.** Strip developer detail (raw command logs, bank toggles,
   manual reboot, per-artifact version pickers) out of the normal path.
6. **Cut the legacy repos loose.** Nothing points at `drdro-software-f4` or `drdro-firmware-f4`
   any more. This is a new board with a new feature set and no installed base — no migration
   bridge, no backwards compatibility, no version-regression concerns.

### Accepted trade-off

A single version means a **software-only change still reflashes the board** — the firmware
binary differs only in its embedded `FW_VERSION`, but the versions must match. Dual-bank +
rollback makes this safe and it costs ~30 s. Accepted deliberately in exchange for
compatibility guaranteed by construction.

*Escape hatch, if the redundant flashes become annoying:* have the firmware report a separate
`proto` compatibility number alongside `version`, gate the mismatch **warning** on `proto`,
and keep the **update** bringing both to the same tag. Do not build this now — just don't
foreclose it.

### Frozen interface

New software must always be able to drive **older** firmware through
`update` → bootloader → YMODEM. If that path breaks, a mismatched unit can never update
itself out of the mismatch. Treat it as a frozen ABI and document it in `updater.py`.

---

## Phase 1 — Version plumbing (single tag)

- [x] Add `version_toml = ["software/pyproject.toml:project.version"]` to `[tool.semantic_release]` in root `pyproject.toml`.
- [x] Reset `software/pyproject.toml` version from `1.7.0` onto the monorepo stream (no installed base — just renumber).
- [x] Update the root `pyproject.toml` header comment: it currently claims "no source file carries the version", which stops being true.
- [x] Confirm `semantic-release version` writes and commits the software version bump alongside the changelog commit. Verified on v1.3.0-beta.1: `software/pyproject.toml` and `software/uv.lock` both stamped in the release commit.
- [x] Confirm `importlib.metadata.version("drdro-software")` reports the release tag after a wheel install. **Caught a real bug:** the wheel carries the PEP 440 spelling (`1.3.0b1`) while the firmware reports the git tag (`v1.3.0-beta.1`); `fw_compat` now reconciles the two.
- [x] Decide and document the version string format shown in the UI (`v1.3.0` vs `1.3.0`) and normalise both sides to it.

## Phase 2 — Release artifacts (CI)

- [x] Add `tools/build-release.sh` at the repo root as the new `build_command`: call `firmware/tools/build-release.sh`, then build the software artifacts.
- [x] Build the software wheel in CI (`uv build` / `hatchling`) into `software/dist/`.
- [x] Produce `drdro-software.zip` = the `software/` tree **plus** the prebuilt wheel, so installation needs no build backend at runtime.
- [x] Extend `SHA256SUMS.txt` to cover the software zip as well as the firmware images.
- [x] Add `software/dist/*` to `dist_glob_patterns` in root `pyproject.toml`.
- [x] Keep asset names fixed (unversioned) so the client resolves by exact match: `drdro-software.zip`, `drdro-mainboard-app.bin`.
- [x] Update the asset inventory comment block at the top of `.github/workflows/release.yml`.
- [x] Extend the job-summary step to list the software artifacts too.

## Phase 3 — Update client (comms layer)

- [x] Repoint `dro/comms/updater.py`: `GITHUB_REPO = "bartei/drdro-mainboard"`, `APP_ASSET = "drdro-mainboard-app.bin"`.
- [x] **Delete the loose asset fallback** at `updater.py:146-147` (`endswith('.bin') and 'app' in name`) — with one repo and one version it can only ever match the wrong artifact.
- [x] Add a release-resolution helper returning both asset URLs for a given tag (software zip + firmware bin) from one API call.
- [x] Implement download-with-SHA256-verification against the release's `SHA256SUMS.txt`; fail closed on mismatch.
- [x] Document the frozen `update`/bootloader/YMODEM interface in the `updater.py` module docstring.

## Phase 4 — Single-step update flow

Ordering matters: fetch everything before mutating anything, so a dropped link can't strand a
unit with new software and old firmware.

- [x] Step 1 — resolve the target release and both asset URLs.
- [x] Step 2 — download zip + bin and verify both checksums **before** any install action.
- [x] Step 3 — stage the firmware binary to a known path (e.g. `/opt/drdro/staged-firmware.bin`) plus a marker recording the target version.
- [x] Step 4 — install the wheel from the zip into the app venv.
- [x] Step 5 — reboot.
- [x] Step 6 — on startup, if a staged marker matches the installed software version and the board reports a different version, flash the **staged local** binary (no network needed at this point).
- [x] Step 7 — clear the marker on success; leave it in place on failure so the flash retries next boot or from the UI.
- [x] Handle the "board already matches" case — skip the firmware step silently rather than reflashing.
- [x] Handle the reverse case (board *ahead* of software) with a distinct message — real when a board is flashed out of band.
- [ ] Verify a failed flash leaves the unit bootable via dual-bank rollback, and that the retry path recovers it. ⚑ retry path is unit-tested; bootability is a hardware claim, unverified

## Phase 5 — Compatibility check

- [x] Delete `COMPANION_FW_VERSION` from `dro/utils/fw_compat.py` — it is anchored to the dead `drdro-firmware-f4` stream (`v0.6.0`) and can never fire correctly again.
- [x] Rewrite the check as software-version vs board-reported `version`, exact match required.
- [x] Keep `parse_fw_version` for ordering so the banner can distinguish "board behind" from "board ahead".
- [x] Update `Board.firmware_update_required` and the home-screen banner wording for the new rule.
- [x] Make the banner's tap target the consolidated update page.
- [x] Unit tests: equal / behind / ahead / unparseable (dev build) — unparseable must stay quiet, as today.

## Phase 6 — UI simplification

The normal path should be: *what you have → what's available → one button → progress → done.*
Everything else moves behind an advanced section.

**Update page — keep:**
- [x] Installed version (read-only).
- [x] Latest available version, auto-refreshed on entry (drop the manual "Refresh" step).
- [x] One **Update** button covering software + firmware.
- [x] A single progress bar for the whole operation.
- [x] A one-line plain-language status ("Downloading…", "Installing…", "Updating board…", "Restarting…").

**Update page — remove or relocate:**
- [x] Remove the raw command log `TextInput` (`update_screen.kv:66-72`) — `run: git fetch --all`, return codes and stderr are developer output. Route it to the Kivy log instead.
- [x] Remove the "Exit Application" button from the update page — unrelated to updating.
- [x] Move "Allow installation of experimental versions" behind the advanced section.
- [x] Replace the release dropdown with latest-only in the normal path; version picking is an advanced action.

**Firmware page — the "Install from GitHub" section becomes redundant** (firmware version now follows the software version):
- [x] Remove the firmware release list, pre-release toggle and per-version install button from the normal path.
- [x] Move bank selection, "Reboot firmware now", manual firmware install and the activity log into an advanced/developer section.
- [x] Decide whether the advanced controls live on a gated section of the update page or stay as a separate Advanced Firmware screen (recommend: keep the screen, drop it out of the normal navigation).
- [x] Keep the progress bar and current-version/active-bank readouts — those are diagnostics worth having.
- [x] Refresh `dro/help/software_update.md` for the new single-step flow.

## Phase 7 — Appliance image (cross-repo: `drdro-arch`)

- [ ] The git checkout at `/opt/drdro/app` is no longer the update mechanism — decide whether the image still ships a checkout at all. ⚑ cross-repo
- [x] Update `PROJECT_FOLDER` / `VENV_PIP` handling in `update_screen.py` for wheel installation.
- [ ] Ensure the staging path (`/opt/drdro/staged-firmware.bin`) is writable and survives reboot. ⚑ cross-repo
- [ ] Coordinate changes to `drdro-arch/build.sh` and `overlay/opt/drdro/app-run.sh`. ⚑ cross-repo
- [ ] Consider installing into a fresh venv and switching a symlink, so a failed `pip install` can't leave the app unbootable. ⚑ optional hardening, not implemented

## Phase 8 — Validation

- [x] Dry run on `dev`: confirm a beta release publishes all assets with the expected names and a valid `SHA256SUMS.txt`. Verified on v1.3.0-beta.1 and -beta.2.
- [x] Verify the client resolves and downloads both assets from a beta tag. Real `ReleaseClient` run against the live release: both assets downloaded, both checksums verified, bundled wheel resolved, staged marker survives the version comparison.
- [ ] End-to-end on hardware: mismatched unit → single-button update → both versions match, no manual steps.
- [ ] Failure injection: kill the network mid-download; kill power between software install and firmware flash; confirm recovery.
- [ ] Only after the above is green, cut a stable tag from `master`.

---

## Files in scope

| File | Change |
|---|---|
| `pyproject.toml` (root) | `version_toml`, `dist_glob_patterns`, `build_command`, header comment |
| `tools/build-release.sh` | **new** — orchestrates firmware + software artifact builds |
| `firmware/tools/build-release.sh` | extend `SHA256SUMS.txt` to cover software artifacts |
| `.github/workflows/release.yml` | asset inventory comment, job summary |
| `software/pyproject.toml` | version reset onto the monorepo stream |
| `software/dro/comms/updater.py` | repo/asset repoint, drop fallback, checksum verify, frozen-ABI note |
| `software/dro/components/screens/update_screen.py` | single-step flow, wheel install, staging |
| `software/dro/components/screens/update_screen.kv` | simplified user-facing layout |
| `software/dro/components/screens/firmware_screen.py/.kv` | demote to advanced; drop redundant release list |
| `software/dro/utils/fw_compat.py` | drop `COMPANION_FW_VERSION`; compare against own version |
| `software/dro/dispatchers/board.py` | mismatch detection wiring |
| `software/dro/help/software_update.rst` | rewrite for the single-step flow |
| `software/dro/comms/release.py` | **new** — release resolution, download, SHA256 verify |
| `software/dro/comms/stack_update.py` | **new** — fetch/verify/stage/install orchestration |
| `software/dro/comms/firmware_apply.py` | **new** — shared flash-with-settings-preservation |
| `software/dro/comms/pending_update.py` | **new** — post-reboot staged-firmware flash |
| `software/dro/utils/version.py` | **new** — single source of truth for the app's version |
| `software/dro/app.py` | startup hook for the staged flash; version via `installed_version()` |
| `software/dro/components/home/fw_update_banner.py/.kv` | mismatch wording; taps through to Update |
| `software/dro/components/screens/setup_screen.kv` | drop the Firmware entry from normal navigation |

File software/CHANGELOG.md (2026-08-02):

# CHANGELOG

<!-- version list -->

## v1.7.0 (2026-07-17)

### Bug Fixes

- **els**: Arm spindle sync when enabling the servo on the ELS page
  ([`7dd9278`](https://github.com/bartei/drdro-software-f4/commit/7dd9278e05b81b693dab0c7471472319611075b1))

### Continuous Integration

- Gate releases on tests, auto-update uv.lock, drop duplicate runs
  ([`e08da79`](https://github.com/bartei/drdro-software-f4/commit/e08da7908dbafdbf999afb97603e1936d1904823))

### Features

- **els**: Custom feed entry for arbitrary pitch/TPI ratios
  ([`0d762f1`](https://github.com/bartei/drdro-software-f4/commit/0d762f16f7857d6cd2d7b71fbf811461f5ecfd77))

- **els**: Hide spindle angular position above 30 RPM
  ([`04400a7`](https://github.com/bartei/drdro-software-f4/commit/04400a7a8b05afdb7d1d1ca3111d8fa9d90af0e4))

### Testing

- Fix PositioningAid tests for the armed/active state
  ([`faceb62`](https://github.com/bartei/drdro-software-f4/commit/faceb62d61e07ce2d161d55537de22fd544874fa))

- Keep ELS widget imports headless-safe (fix release CI)
  ([`53a99ef`](https://github.com/bartei/drdro-software-f4/commit/53a99ef18aea6bd15c8446ad8b171c2467061617))

## v1.6.0 (2026-07-05)

### Bug Fixes

- Positioning aid scale is now unit-independent
  ([`ab39232`](https://github.com/bartei/drdro-software-f4/commit/ab39232f615e343be16c282253cf879ba0ced978))

### Features

- Synthesized approach beeper (PT 855 G2 audible cue)
  ([`41d2e6b`](https://github.com/bartei/drdro-software-f4/commit/41d2e6b84c7c123d4412befcce8b689040334261))

## v1.5.0 (2026-07-05)

### Bug Fixes

- Make beep() actually play — audio was a stub since the port
  ([`b0dd210`](https://github.com/bartei/drdro-software-f4/commit/b0dd21050ac32b1413c793c03c5fea90138ec320))

- Rename PositioningAid on_target_color property — the on_ prefix is Kivy handler syntax
  ([`b3b95ed`](https://github.com/bartei/drdro-software-f4/commit/b3b95edfc26c96cd76711a8ab885af56c498fe8c))

### Features

- Finalize the distance-to-go positioning aid (PT 855 G1/G2)
  ([`ef6610e`](https://github.com/bartei/drdro-software-f4/commit/ef6610e7b1d5e104bf84c18615b15ad175c23a82))

- Per-axis in-position tolerance for the positioning aid
  ([`af779f8`](https://github.com/bartei/drdro-software-f4/commit/af779f8afe6e2382218492969b5d9bf51426fe1a))

## v1.5.0-beta.1 (2026-07-03)

### Chores

- Move documentation website to its own repo
  ([`dc9ef38`](https://github.com/bartei/drdro-software-f4/commit/dc9ef38eab141dc766af1ef43ff71c151523f1bd))

### Continuous Integration

- Add mock static content deploy pipeline
  ([`74597e2`](https://github.com/bartei/drdro-software-f4/commit/74597e2c4e4899b4fa04b566e3e3553722081851))

- Remove static content deploy pipeline
  ([`1bf39c8`](https://github.com/bartei/drdro-software-f4/commit/1bf39c8bd6ab2680d3932f9ae8823542c6948279))

### Documentation

- **website**: Add documentation site and wire static deploy
  ([`ceacb6a`](https://github.com/bartei/drdro-software-f4/commit/ceacb6ab5a3b7be03b504abe20c3a518c30ec744))

- **website**: Add Videos page with creator + community demos
  ([`2521e64`](https://github.com/bartei/drdro-software-f4/commit/2521e64c907b5037001c95dd65fb6ca6d3637cb7))

- **website**: Use the drDRO logo for site brand and favicon
  ([`807bba5`](https://github.com/bartei/drdro-software-f4/commit/807bba5a88f8b94f139d2e1fdd5629adade988c0))

### Features

- Add distance-to-go target and graphic positioning aid to coordbars
  ([`45772ed`](https://github.com/bartei/drdro-software-f4/commit/45772eda3fb8051f3d5988cd8ba683e5bb1b0bec))

## v1.4.0 (2026-07-02)

### Bug Fixes

- **update**: Point software updates at drdro-software-f4, not RCP
  ([`5a0a83a`](https://github.com/bartei/drdro-software-f4/commit/5a0a83acdef850f05af72d0fd99ab199ae2003ac))

### Code Style

- **ui**: Soften RetroProgressBar fill, drop the frame
  ([`1c18ce6`](https://github.com/bartei/drdro-software-f4/commit/1c18ce69276756e2720d43a2ad5ec4f3eb9070cf))

### Continuous Integration

- Beta prereleases on dev; fold beta notes into stable releases
  ([`61a1d21`](https://github.com/bartei/drdro-software-f4/commit/61a1d21108cc91be97245f2fe334cd4bdd2db502))

### Documentation

- Resume + design notes for filter UI, profiles, compat banner, update-screen fix
  ([`8d136d8`](https://github.com/bartei/drdro-software-f4/commit/8d136d8fc04233c532bbc99a457e5c4e89bc3183))

### Features

- **profiles**: Machine profiles + firmware-update settings backup/restore
  ([`553d8b5`](https://github.com/bartei/drdro-software-f4/commit/553d8b5487f9b0534fe8bf8c1212a1c2e8bb38e6))

- **scales**: Encoder filter setting on the input screen (scales.filt)
  ([`c7f85c3`](https://github.com/bartei/drdro-software-f4/commit/c7f85c364ee93559b2b8f903d3ff39d6c38c6e37))

- **update**: Firmware-compat check + tap-to-update banner on home
  ([`3e2dd0a`](https://github.com/bartei/drdro-software-f4/commit/3e2dd0afbc016f9bb640043d5dd34b18264d505d))

## v1.3.0 (2026-07-01)

### Chores

- Add shell.nix for NixOS dev
  ([`663f7ef`](https://github.com/bartei/drdro-software-f4/commit/663f7efef8615c4419ad74bdbee65381552a2490))

### Features

- **servo**: Board-owned indexing feedrate; drop max-speed override
  ([`77edec9`](https://github.com/bartei/drdro-software-f4/commit/77edec92a3ac3907fc060a6a4822e2daf4a9b5fb))

- **ui**: RetroProgressBar — solid-fill, 1px-frame progress bar
  ([`0e42489`](https://github.com/bartei/drdro-software-f4/commit/0e42489cdc2fcbfdaec2f037d8e20a547768d24c))

## v1.2.0 (2026-06-30)

### Features

- **ui**: Declutter home — hide debug ribbon by default, add Stats screen
  ([`c616da7`](https://github.com/bartei/drdro-software-f4/commit/c616da724456e1196482d8fa88da18efb558bba6))

## v1.1.3 (2026-06-30)

### Bug Fixes

- **servo**: Jog no longer triggers a flash save (200 ms position stall)
  ([`3bc2cd9`](https://github.com/bartei/drdro-software-f4/commit/3bc2cd91b31922fdd8783d9bde20a3eaa466d23d))

## v1.1.2 (2026-06-30)

### Performance Improvements

- **board**: Rate-limit sta poll to target (subtract round-trip); show sta Hz
  ([`7b9fc0e`](https://github.com/bartei/drdro-software-f4/commit/7b9fc0e00c16da293a1429a8ee2eceeaaaa05a8c))

## v1.1.1 (2026-06-30)

### Bug Fixes

- Remove Sentry, fix TraceOutput leak, demote debug print (Phase 6 polish)
  ([`3fbe6e4`](https://github.com/bartei/drdro-software-f4/commit/3fbe6e4cf0c2a6999d4aa13f47e2c65e49056285))

## v1.1.0 (2026-06-30)

### Features

- **firmware**: Robust GitHub release fetch (certifi) + GPL relicense
  ([`4e1b8fc`](https://github.com/bartei/drdro-software-f4/commit/4e1b8fca3886d7aa4ac30c3479544487b25407df))

## v1.0.0 (2026-06-30)

- Initial Release

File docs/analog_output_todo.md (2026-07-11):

# Analog outputs (2× 0–10 V VFD ref) — todo (LIVE tracker)

> Detail + rationale in `analog_output_design.md`. Scope: 2× 0–10 V via one GP8403
> dual I²C DAC on the shared I²C1 expansion bus (PB8/PB9), non-isolated. 4–20 mA
> dropped (2026-07-10). **In the netlist + reviewed 2026-07-10** (`Netlist_Schematic1_2026-07-10.net`).

## Phase 0 — Decisions
- [x] 0–10 V only; 4–20 mA dropped (user, 2026-07-10)
- [x] Non-isolated (board/VFD shared cabinet ground)
- [x] Part: GP8403-TC50-EW dual 12-bit I²C→0–10 V (C3152007)
- [x] Bus: **shared I²C1 expansion bus** (PB8/PB9), addr 0x58 (not the bit-bang bus)

## Phase 1 — Schematic (DONE, verified in netlist)
- [x] U20 GP8403 placed; VCC → VIN (24 V); GND + EP → GND
- [x] V5V → C45 (1 µF) to GND
- [x] SCLK/SDA → SCL/SDA (I²C1); pull-ups R74/R14 4.7 k reused; A0/A1/A2 → GND (0x58)
- [x] VOUT0→AO0, VOUT1→AO1; each 1 µF (C42/C43) + SMAJ12A TVS (D5/D6, C113957) to GND
- [x] 47 Ω series R per output (R75/R76)
- [x] Output terminal CN9 (WJ15EDGRC-3.81-4P): AO0 / AO1 / GND / GND
- [ ] Optional: local 0.1 µF + 10 Ω/ferrite + 10 µF RC on VCC (24 V-bus noise)
- [ ] Reserve I²C addr 0x58 — no future DB9-bus expansion device may reuse it

## Phase 2 — Layout
- [ ] Place U20 away from buck/inductor + motor-driver noise
- [ ] Short VOUT traces; TVS + cap at the connector end
- [ ] AO COM to solid GND plane; keep any VCC filter local

## Phase 3 — Firmware
- [ ] I²C1 driver reaches U20 @ 0x58 (share bus w/ any DB9 expansion devices)
- [ ] Set 0–10 V mode (reg 0x01 = 0x11) at boot; optional NVM persist
- [ ] RPM→12-bit scaling per VFD; write VOUT0 (0x02) / VOUT1 (0x04)

## Phase 4 — Review
- [x] Netlist review 2026-07-10: AO block wiring correct, no dangling nets, EP→GND,
      addr 0x58, VOUT protection present, caps 1 µF per official datasheet
- [ ] Re-confirm JLCPCB stock/part-class for C3152007 before order

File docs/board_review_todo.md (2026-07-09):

# Full-board review findings — 2026-07-04

Netlist: Netlist_Schematic1_2026-07-04.net (145 comp / 120 nets at review time).
Full audit incl. MCU pin-function check vs F411 AF table, reset, boot0, all I/O.

> **Re-verified 2026-07-04** against the current export (**171 comp / 133 nets,
> zero dangling nets**): findings below still hold; deltas ticked inline.
> `STATUS.md` is the authoritative status.

## 🔁 Adversarial re-review — 2026-07-09 (`Netlist_PCB1_2026-07-09.net`, 177/133)
Deterministic parse (both `.tel` and `.net`) + full net-by-net trace + datasheet
pinout checks (STM32F411, W5500 vs WIZnet ref sch, AM26LV32E, TLP2309, SIT3088,
ULN2003, LMR33630). **No critical/board-killer defects.** Zero dangling nets,
**zero pins on >1 net (no shorts)**, all IC power/GND/EP pins resolved, all rails
sourced. Part numbers confirmed (U2 LMR33630ADDAR, U5 SIT3088ETK, U7–U11
AM26LV32EIDR, U12–17 TLP2309, U18 ULN2003ADR, U19 W5500, D1 SMDJ36CA, D2 SL10100).
New / changed items (full list + detail in `STATUS.md` OPEN):
- ✅ Encoder **5-chip-per-DB9 split now done** (U7–U11); SPI-NSS pull-up added (R72);
  W5500 AVDD-ferrite / 1V2O 10nF / TOCAP 4.7µF / EXRES 12.4k all match WIZnet ref.
- ✅ **CN1** — NON-ISSUE: it's the pluggable mating plug in the BOM, intentionally unwired.
- ✅ **Optos OK as designed** — keep board-5V sinking inputs; domain change = pin swap if ever wanted.
- ⬜ **Add ESD/surge on IN1–6**: SMAJ6.0CA (C466511) TVS→GND per line (+opt ~100Ω series R).
- ✅ **Index-Z DESCOPED** (user 2026-07-09) — front-end final, A/B only.
- ✅ **I²C pull-ups added** (R14/R74 4.7k→3V3). ESD footprints still optional.
- ✅ **U5 RS485 part change** — SIT3088ETK OOS → SP3485EN-L/TR (C8963, SOIC-8, drop-in).
- 🔧 **Replace D1 TVS** → SMCJ30A (C408374 / C135160), uni, 30V, same SMC footprint.
- 🔍 CIN 1206 / COUT 22µF-0805 case + V-rating; per-IC 0.1µF (opto Vcc). (layout)
- ✅ **Layout reviewed** (Gerber 2026-07-09): 4-layer, solid GND plane, buck EP
  stitched, receivers at DB9s, W5500 decoupling tight. See STATUS.md.

## 🔴 Critical (blocks bring-up)
- [x] MCU VDD pin 19 + VSS pin 18 — FIXED & verified: 18→GND, 19→3V3, all 5
      VDD/VSS pairs now wired.

## 🟠 Should-fix
- [x] Orphaned motor pull-ups — FIXED: reconnected to M*_OUT nets (+ CN6/CN7),
      no more dangling.
- [x] M3_DIR moved off PC13 → PC3. Also M2_STEP/DIR, M3_STEP → PC0/PC1/PC2.
      All normal GPIOs; vacated pins freed; no double-assignment. Verified all
      7 channels MCU→ULN→connector.
- [ ] 🔵 Connector grouping heads-up: motor 2 split across CN6 (M2_STEP) and
      CN7 (M2_DIR). Electrically fine; regroup per-motor if desired. CN6/CN7
      are signal-only (no GND/5V) → assume opto-isolated drivers, COM→driver +V.
- [ ] I2C: add SDA/SCL pull-ups + ESD footprints (expansion bus, still missing).
- [ ] Encoder front-end: only 3 shared quad receivers (A/B, no Z) — the agreed
      5-chip-per-DB9 + index-Z restructure is still owed. See encoder_input_todo.md.

## ✅ Verified correct
- [x] All 5 encoders on TIM1-5 CH1/CH2 (hardware quadrature) — pin choice good
- [x] USART1 / I2C1 / SPI2 / SWD / crystal on valid AF pins
- [x] Reset circuit (pull-up + steering diodes + button)
- [x] BOOT0 circuit (pull-down + button)
- [x] Encoder receivers direct to MCU; no 5V on non-tolerant pins
- [x] Decoupling improved (11 caps on 3V3)

## 🔵 FYI / firmware
- STEP pins not on free timers (TIM1-5 = encoders) → GPIO/DMA step gen only
- ENC5 firmware: use TIM5 (AF2) not TIM2
- JTAG pins repurposed — SWD-only debug (fine)

## W5500 Ethernet (added 2026-07-04) — mostly correct
- [x] Crystal load caps → 18pF (C28/C31). CORRECT for the X322525MOB4SI which
      is a 12pF-CL crystal (2×(12−~3pF stray)=18pF → ~12pF effective CL). Note:
      earlier "match to 18pF" was right by luck; crystal is 12pF-CL not 18pF.
- [x] Crystal case pins (X3 pins 2,4) grounded.
- [ ] SPI NSS (PB12→W5500 SCSn): wiring correct. FIRMWARE: drive PB12 as GPIO
      software CS (not HW-NSS) so SCSn frames each W5500 SPI transaction (VDM).
- [ ] 🟠 Optional: add ~10k pull-up on SCSn→3V3 (defined deselect at boot).
- [ ] 🔵 Optional: add 1MΩ feedback (XI-XO) + 0Ω series on XO per ref (Fig 3).
- [x] SPI mapping correct (MOSI-MOSI/MISO-MISO, SCSn→PB12, no swap); INTn/RSTn
      →PC6/PC7 with pull-ups — verified vs datasheet Fig 4
- [x] EXRES1 12.4k 1%→AGND, 1V2O 10nF, TOCAP 4.7µF — all per WIZnet ref
- [x] AVDD ferrite+decoupling, center-tap 3V3 via ferrite+0.1µF, PMODE=111
- [x] TX/RX pairs + MagJack + LEDs correct; NC pins (7,12,13,18,24,26,46,47) ok

## ⚪ Minor / carryover
- [ ] RESET optional 100nF cap to GND
- [x] SPI (PB12-15) now wired to W5500 (SCSn/SCLK/MISO/MOSI + INTn/RSTn) — verified
- [ ] Carryover verify: U5 SIT3088 EP→GND, crystal load caps vs CL, ISO_IN
      firmware pull-ups

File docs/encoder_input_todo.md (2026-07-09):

# Encoder input stage — todo (LIVE tracker)

> Detail + rationale live in `encoder_input_design.md`. As-built (verified against
> `Netlist_PCB1_2026-07-09.net`, 177 comp / 133 nets) = **5 quad receivers, one
> AM26LV32E per DB9, A/B only**. The 5-chip split is DONE; **index-Z is DESCOPED**
> (user, 2026-07-09) → front-end is FINAL.

## Phase 0 — Design decisions
- [x] Approach: universal biased differential receiver, no mux, no mode select
- [x] Receiver part confirmed: AM26LV32E (3.3V out safe for PA0; ±14V rugged inputs)
- [x] Design of record: one quad receiver per DB9 (5 chips), A/B/Z + spare

## Phase 1 — Circuit values
- [x] Bias divider = 2.2k/2.2k (stiff vs 4–17kΩ receiver Rin); ref ~2.0–2.35V
- [x] A+ pull-up = 2.2k to 5V (fail-safe high)
- [x] No termination (would collapse the single-ended reference)
- [ ] Optional ~150Ω series protection R per DB9 line — not placed

## Phase 2 — A/B front-end + 5-chip split (AS BUILT, verified 2026-07-09)
- [x] NC7SZ157 muxes + TTL_SEL removed; receiver outputs direct to MCU
- [x] **5 quad receivers, one AM26LV32EIDR per DB9: U7=J1, U8=J2, U9=J3, U10=J4, U11=J5**
- [x] Per-line 2.2k pull-up (A+/B+) / 2.2k+2.2k divider (A−/B− → ~2.5V) / no term
- [x] Receivers enabled: pin4(G)=3V3; spare ch3/4 inputs tied to defined levels,
      outputs (pin11/13) left open
- [x] Right-angle DB9 DS1037-09FNAKT74-0CC used (J1–J5)
- [x] Connector mapping J1→ENC1 … J5→ENC5 (each its own receiver+axis) verified
- [x] Outputs on correct MCU pins: PA8/9, PA5/PB3, PA6/7, PB6/7, PA0/1 (TIM1–5)
- [x] No dangling nets / no shorts in front-end
- [ ] Note: receiver output is inverted vs input (A+ lands on the B-input pin);
      consistent across all 5 → handle as a firmware count-direction flip only

## Phase 3 — index-Z — DESCOPED (user decision 2026-07-09)
- [x] **Z inputs will never be connected.** No work owed. DB9 pin 6 stays free;
      each chip's 2 spare receiver channels stay tied off. Encoder front-end is
      FINAL: 5× AM26LV32E, A/B only, one per DB9.
- [x] JLCPCB stock: 5× AM26LV32EIDR already placed (re-confirm ≥1000 before order)

## Phase 4 — I²C expansion bus
- [x] Pull-ups added: R14 (SDA) / R74 (SCL) = 4.7k to 3V3. DONE 2026-07-09.
- [ ] Optional: ESD footprints on SCL/SDA where they leave via the DB9s.

## Phase 5 — Review
- [x] Re-exported netlist + Gerber re-reviewed 2026-07-09 (front-end verified;
      receivers placed at their DB9s, good SI). Front-end FINAL.

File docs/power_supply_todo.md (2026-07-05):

# Power supply todo

> ⚠️ HISTORICAL working notes (design evolution). Many items are superseded/done.
> See **STATUS.md** for the authoritative current state and open items.
>
> **Re-verified 2026-07-04** vs `Netlist_Schematic1_2026-07-04.net` (171/133, no
> dangling nets): buck + FB divider (4.82–5.20V) + VCAP 2.2µF + RS485 GPIO-DE all
> intact. **Designator note:** the current export has buck = **U2** (LMR33630),
> inductor = **U3** (CYA0630-10µH), AMS1117 = U4, RS485 = U5 — the design docs'
> older "U1"/"U6" references map to these.

## Phase 0 — Part selection
- [x] Select buck controller (LMR33630ADDAR)
- [x] Select inductor (CYA0630-10UH, 10µH)
- [x] Verify JLCPCB stock ≥1000 units, no lifecycle warnings
- [x] Work out FB divider / inductor / cap sizing

## Phase 1 — Schematic capture
- [ ] Place LMR33630ADDAR + support components per power_supply_design.md
- [ ] Confirm footprint (HSOIC-8 PowerPAD / DDA) matches JLCPCB part
- [ ] Route thermal pad to ground plane with via array

## Phase 2 — Review (power stage)
- [x] Send netlist back for review (Netlist_Schematic1_2026-07-03.net)
- [x] Fix: U1 PGND tied to GND net (verified round 2)
- [x] Fix: R3 100k moved to VCC→PG; PG no longer floating (verified round 2)
- [ ] Optional: rename U6 (inductor) to L-prefix for BOM clarity
- [ ] Optional: recenter FB trim range (swap R30 20k→22-24k) if desired

## Phase 2b — Full-board review findings (round 2, 2026-07-04)
- [ ] 🟠 VCAP C16: change 10µF → 2.2µF X7R (STM32F411 spec)
- [ ] 🟠 Add local 100nF decoupling per logic IC (esp. 10× NC7SZ157 muxes)
- [ ] 🔍 RS485 bias R57/R63=120Ω: KEEP if staying with auto-direction (mark held by bias); only raise to ~560-680Ω if moving to GPIO/always-on DE
- [ ] Decide RS485 speed: circuit good to ~250kbps (500k marginal). For faster, GPIO-DE off USART TC (F411 has no hardware DEM) or speed up Q1 (R1→4.7-10k + 100pF speedup cap)
- [ ] 🔍 Confirm U5 SIT3088 DFN exposed pad tied to GND on layout
- [ ] 🔍 Verify crystal load caps C18/C19 (12pF) match X1 CL
- [ ] ⚪ ISO_IN1–6: rely on MCU internal pull-ups; consider 10k externals
- [ ] ⚪ ULN2003 out pull-up via LED+1.5k to 5V — verify high level for ext driver
- [ ] ⚪ U16 unused receiver channels 3&4: tie inputs to defined level
- [ ] ⚪ NRST: optional 100nF to GND
- [ ] Re-export netlist and re-review after fixes

## Phase 2c — Round 3 review (RS485 DE→MCU, 2026-07-04)
- [x] DE control moved to MCU GPIO PA11 (Q1/R1/R2 removed) — verified
- [x] RS485 bias/term redone: R28/R30=680Ω bias, R33=120Ω term — verified
- [x] RJ45 removed (intended); SWD still on header
- [x] 🔴 FB divider fixed: top 51k+33k=84k, bottom 20k+2k trim → 4.82–5.20V (verified round 4)
- [x] 🟠 UART_DE pull-down added: 10k to GND (verified round 4)
- [x] ⚪ Activity LEDs removed cleanly — no dangling nets (verified round 4)

## Phase 2d — Round 4 (2026-07-04): still-open round-2 items
- [x] 🟠 VCAP cap → 2.2µF (STM32F411 spec) — done, verified 2026-07-04
- [ ] 🟠 Verify 100nF local decoupling per logic IC (~8 caps for the digital rail)
- [ ] 🔍 U5 SIT3088 exposed pad tied to GND on layout
- [ ] 🔍 Crystal load caps (12pF) vs X1 CL
- [ ] ⚪ ISO_IN internal pull-ups in firmware; U16 unused RX inputs; NRST cap
- [ ] Reference: RS485 good to 10 Mbps (USART1/APB2, ~12.5 Mbps ceiling); SPI2 free on PB12-15

## Phase 3 — Prototype bring-up
- [ ] Verify 5V rail across 0–2A load
- [ ] Check efficiency / thermal at 2A continuous
- [ ] Confirm ripple/EMI acceptable near sensitive analog sections

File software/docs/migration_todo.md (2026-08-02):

# drDRO Software — Migration & Port Todo

Phased one-liner tracker. Detail & rationale in `migration_design.md`. Tick `[x]` as items
land; keep the design doc as the source of truth. **D2/D3/D4/D5 confirmed; D1 defaulted to
`dro`; D7 (firmware-update source) deferred to Phase 5.**

## Phase 0 — Decisions & repo init
- [x] uv project scaffold (`pyproject.toml`, `.python-version`, `.gitignore`, `dro/` package)
- [x] Draft design doc + this tracker
- [x] Port `CLAUDE.md` coding standards from RCP (kivy.logger, naming, KV pattern)
- [x] Port `README.md` (host app overview + build/run)
- [x] `master` → `main`; first commit; `uv lock` green
- [x] Resolve key decisions: D2 (extend `sta`), D3 (asyncio queue), D4 (ratios in Python),
      D5/D6 (firmware = source of truth for persisted settings). D1=`dro`; D7 deferred.
- [ ] Confirm package name (D1) and apply `rcp.` → `dro.` rename convention

## Phase 0b — Cross-repo firmware prerequisite (drdro-firmware-f4)
- [ ] Extend firmware `sta` to also emit `servo.tgt` + `servo.mode` (one `respKV` pair + native
      test) — needed before Phase 2 fast loop is finalized. **Tracked in the firmware repo.**

## Phase 1 — Protocol client (driver replacement core) — done 2026-06-29, HW-verified
- [x] `dro/comms/protocol_client.py`: `serial.Serial` owner, framed request/response
- [x] Response reader: read until blank line, parse `key=value`, verify `crc=HH` (`parse_response`)
- [x] RS-485 turnaround-glitch tolerance + retry (glitch heuristic on unknown command/variable + crc fail)
- [x] `get` / `set` (with array `idx`) / `settings` / `sta` / `version` (`help` via `command()`)
- [x] `save` / `load` (board flash)
- [x] Optional `*HH` request checksum (`request_checksum` flag; HW-validated end-to-end)
- [x] `MAX_ERROR_COUNT` resilience / connected-state semantics
- [x] Bus serialization (D3): asyncio lock-guarded queue + single-thread executor; never blocks Kivy
- [x] Unit tests (15) against a firmware-accurate `FakeSerial` — crc/retry/error/link-state
- [x] **HW-verified** against the board over `/dev/ttyACM2`: version/sta/get/set/settings/RO-error,
      checksummed requests, read+write round-trips, restore. All CRC-correct, link stayed up.
- [x] Keep `dro/utils/ctype_calc.py` (encoder-wrap helper ported in Phase 2)

## Phase 2 — Dispatchers re-pointed to the protocol — done 2026-06-29, HW-verified
- [x] `board.py`: owns `ProtocolClient`; async poll loop (`run`/`poll_once`) replaces the
      Clock-driven Modbus refresh; sync↔async bridge (`write`/`write_persisted`/`cached`/`_spawn`)
- [x] Fast-poll: single-round-trip `sta` → `map_sta` (scales.pos/speed, servo.pos/speed/tgt/mode)
- [x] `servo.py`: `maxSpeed/acc/jog`→`servo.max/acc/jog`; `direction`→`servo.tgt`; `servoEnable`→`servo.mode`;
      board-as-source-of-truth sync on connect (`_sync_from_board`, write-back suppressed)
- [x] `axis.py`: `_set_sync_ratio` → live `set scales.num/den` (never saved, D4); `toggle_sync` → `set scales.sync`
- [x] `input.py`: scale position/speed from the `sta` mapping
- [x] `els.py` ported; `ctype_calc`, `saving_dispatcher`, `formats`, `axis_transform` ported
- [x] Board folds `diag.cycles`/`diag.interval` into `fast_data_values` via a low-rate `get`
      (statusbar *widget* itself is Phase 4 UI)
- [x] Settings flow wired (Phase 3 overlaps): read board on connect (no push), `set`+debounced
      `save` on persisted UI change, ratios live-only
- [x] Unit tests (map_sta + cache, 4) + **HW harness**: Board+dispatchers drive the live board —
      connected, fast_data_values populated, servo synced from flash, persisted + live writes round-trip
- [ ] Verify identical UI behaviour vs RCP on the bench — deferred to Phase 4 (UI not built yet)

## Phase 3 — Settings: firmware = source of truth (landed with Phase 2)
- [x] On connect: **read** persisted settings (`servo.max/acc/jog`) → sync Python (no push)
      (`Board._refresh_settings` + `ServoDispatcher._sync_from_board`)
- [x] Removed `on_connected` push of `maxSpeed`/`acceleration`; replaced with read-back
- [x] On UI change of `servo.max/acc/jog`: `set` + debounced `save` (`Board.write_persisted`)
- [x] `scales.num/den`: derived in Python, `set` on connect/change, **never `save`** (D4)
- [x] `scales.sync` / `servo.mode`: read-on-connect to sync UI; `set` on change; not saved (D5)
- [x] Dropped Modbus `address` from `config.ini` (client has no addressing)

## Phase 4 — UI feature parity port (1:1) — built & rendering 2026-06-29
- [x] Screens (19) + `.kv` ported; Manager instantiates them all at startup
- [x] Home modes + bars (Index/ELS/Jog/DRO, coordbar/servobar/elsbar/jogbar/statusbar)
- [x] Popups (keypad/help/mode/feeds/ssid), Widgets (number/dual/boolean/dropdown/…), Plot (+circle/line/rect)
- [x] Pattern dispatchers (circle/line/rect) + `axis_transform` + `formats` + `els` + `saving_dispatcher`
- [x] Platform utils (`platform.py`, `kv_loader.py`), `feeds.py`, help `.rst`, fonts/pictures/sounds
- [x] `app.py` (resource paths, serial cfg → Board, `board.start()`) / `main.py` / `manager.py` / `appsettings.py`
- [x] Kept RCP git/pip self-update screen (D7 — both updaters coexist)
- [x] `rcp.`→`dro.` rewrite incl. bare KV `#: import` targets; `~/.config/drdro-software` config dir
- [x] **App builds & renders headless (Xvfb+SDL2/GL)**: all 19 screens instantiate, 51 KV files load,
      home screen renders live against the board (screenshot). Package version v0.1.0 shown.
- [x] Interactive parity pass on a real desktop (Wayland/XWayland, DISPLAY :0): all 24 screens
      toured + rendered, all 4 home modes (Index/ELS/Jog/DRO), keypad popup, plot canvas; servo
      values read live from the board (720/120), nmcli live, non-Pi system detection. v0.1.0.
- [x] Live-motion check (servo jog + index) HW-verified through the UI: jog ramps servo pos,
      index counts stepsToGo to 0 and completes; servo bar shows enabled + live position.
      Fixed a port bug found here — servo mode command was reverted by the laggy `sta` read
      (async write lag); now held until the board confirms it (commit e1a1dc5).

## Phase 5 — Firmware update & bank management — done 2026-06-29, HW-verified
- [x] `dro/comms/ymodem.py` (YMODEM sender, CRC-16/1024B, progress cb; port from `dro_update.py`)
- [x] `dro/comms/updater.py` (`FirmwareUpdater`: GitHub release list/download + flash flow
      update→info→flash<bank> YMODEM→bank<n>→boot; version/bank/reset helpers)
- [x] Bootloader CLI driven via the framed client (`info`, `flash <n>`, `bank <n>`, `boot`)
- [x] `ProtocolClient.run_blocking` (exclusive serial) + `Board.pause/resume` (yield the bus)
- [x] Firmware screen: current version, active-bank field, **boot-bank selector**, **manual Reset**,
      GitHub version list (+pre-release toggle), Install, **upload progress bar**, status log;
      registered in manager + "Firmware" setup button
- [x] **HW-verified**: flashed a local `.bin` into the inactive bank over RS-485 (YMODEM, 49592 B),
      set active, booted — version + active bank updated (1→0). UI rendered with live data.
- [x] GitHub fetch verified end-to-end on the desktop: refresh→download→flash→boot installed the
      real `v0.4.3` release (TLS via certifi so it works on NixOS); board ran v0.4.3 after.
- [ ] Optional: expose `rollback` / `erase` / `crc` bootloader commands in the UI (have the plumbing)

## Phase 6 — Release & polish — done 2026-06-30
- [x] CI (GitHub Actions): `ci.yml` (uv + pytest) + `release.yml` (python-semantic-release);
      repo pushed to `bartei/drdro-software-f4`; releases cutting (software v1.1.0, firmware v0.4.4)
- [x] **Sentry removed** (per request) — dropped the init + `sentry-sdk` dep (it even pointed at
      RCP's DSN); logging stays on kivy.logger (comms layer intentionally stdlib)
- [x] RCP dead-code cleanup: fixed the `TraceOutput`/`exit_stack` latent bug (Ctrl+T now a safe
      start/stop trace toggle); demoted a stray keypad `print` to `log.debug`
- [x] User-facing Modbus→protocol migration notes in the README
- [x] GPL-3.0-or-later relicense (both repos)
- [ ] Optional later: implement `beep()` (currently a no-op stub) using the bundled sounds

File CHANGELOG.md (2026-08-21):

# CHANGELOG

## v1.3.0 (2026-08-21)

## v1.3.0-beta.3 (2026-08-20)

### Bug Fixes

- Use ferrite beads with higher stock availability on jlcpcb. fix speed reporting
  ([`5cc9490`](https://github.com/bartei/drdro-mainboard/commit/5cc9490ae9a505446319f95aa2d34cb9a4776cb9))

### Documentation

- **update**: Record beta validation results in the tracker
  ([`e7353cf`](https://github.com/bartei/drdro-mainboard/commit/e7353cf87e7776846d4aa16fd7e5fcab3b6a1de8))

## v1.3.0-beta.2 (2026-08-03)

### Bug Fixes

- **compat**: Treat PEP 440 and git-tag prerelease spellings as equal
  ([`aaab481`](https://github.com/bartei/drdro-mainboard/commit/aaab481e47ece5459d86a49f1bf130876f568bc1))

## v1.3.0-beta.1 (2026-08-03)

### Bug Fixes

- **tests**: Pin the Kivy window provider so headless runs can't exit(102)
  ([`fd5e359`](https://github.com/bartei/drdro-mainboard/commit/fd5e359b433da76ac85da117ceddb181c7004c8f))

- **tests**: Wait for accept() before dropping the mock board connection
  ([`b08640a`](https://github.com/bartei/drdro-mainboard/commit/b08640a26a6422275232b5209a5d4593da788bc6))

### Chores

- **hardware**: Update board project file; remove H723 variant design notes
  ([`4ed6759`](https://github.com/bartei/drdro-mainboard/commit/4ed6759ff717ab47c1a4e2f521bbf1c3715ec5d3))

- **software**: Add drDRO host software — Kivy port with Ethernet transport
  ([`e539b67`](https://github.com/bartei/drdro-mainboard/commit/e539b67091efeb1d515c2a923027dc1f214adbb4))

### Continuous Integration

- **release**: Surface host-test failures as annotations
  ([`8830f8b`](https://github.com/bartei/drdro-mainboard/commit/8830f8b967db2692c5010840cca3e57955a71d82))

### Features

- **update**: Single-version stack releases with one-step updates
  ([`6e24594`](https://github.com/bartei/drdro-mainboard/commit/6e24594c8ff1fcbf513d44d6a5ecc492fefd4e0f))

## v1.2.0 (2026-08-01)

### Features

- **protocol**: Configurable RS-485 baud up to 1 Mbaud (com.baud)
  ([`a6545db`](https://github.com/bartei/drdro-mainboard/commit/a6545dbf303b7801559bfebf5b0e0ef854b683f7))

## v1.1.1 (2026-08-01)

### Bug Fixes

- **boot**: Harden the bootloader-jump path found by RS-485 update testing
  ([`bcfb676`](https://github.com/bartei/drdro-mainboard/commit/bcfb676559fb0302801f65e07faffac5d21c8b49))

## v1.1.0 (2026-08-01)

### Bug Fixes

- **boot**: Survive a hung I2C bus at startup
  ([`73e19b1`](https://github.com/bartei/drdro-mainboard/commit/73e19b1443aecc818b0317f092e7e6ff6a3b056a))

### Features

- **protocol**: Report encoder count as read-only scales.count
  ([`0dc3c82`](https://github.com/bartei/drdro-mainboard/commit/0dc3c824603b56a8e88b144aa905cd6c10366872))

## v1.0.1 (2026-08-01)

### Bug Fixes

- **release**: Regenerate CHANGELOG.md on every release
  ([`ca3e73d`](https://github.com/bartei/drdro-mainboard/commit/ca3e73d9b84efee794b91dc2e629c2db601065ca))

## v1.0.0 (2026-08-01)

- Initial Release

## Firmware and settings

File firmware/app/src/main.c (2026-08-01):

/**
 * Copyright © 2026 <Stefano Bertelli>
 * GPL-3.0-or-later. See LICENSE.
 *
 * drDRO mainboard V1.5 application — entry point and clock tree.
 * Runs from the Exec region (0x08020000) under the IAP bootloader in sector 0;
 * see shared/Bootloader.h for the flash map and the handoff contract.
 */
#include "main.h"
#include "cmsis_os.h"
#include "gpio.h"
#include "tim.h"
#include "usart.h"
#include "i2c.h"
#include "Net.h"
#include "NetCli.h"
#include "Ramps.h"
#include "Protocol.h"
#include "SettingsStore.h"
#include "Din.h"
#include "Aout.h"
#include "FwUpdate.h"
#include "Bootloader.h"   /* APP_EXEC_BASE — keep VTOR in sync with the linker/bootloader */

rampsHandler_t RampsData;

/* Vector table relocated to RAM so interrupt entry (esp. the motion ISR) doesn't fetch
 * from flash — lets the step ISR keep running while flash is erased/programmed (settings
 * /bank save, Ethernet update into a bank). 512-byte aligned (VTOR requires alignment
 * >= table size, ~101 vectors). */
static uint32_t g_ramVectors[128] __attribute__((aligned(0x200)));

void SystemClock_Config(void);

/* Hand off to the IAP bootloader by JUMPING to 0x08000000 — same mechanism as the
 * proven baseline. (BOOT0 is pulled down on this board so a reset would also be
 * safe, but the jump preserves identical host-observed behavior and the no-init
 * BOOT_FLAG.) Tears down the running app (mask IRQs, stop SysTick, clear NVIC,
 * switch to MSP) then branches to the bootloader's reset vector. */
void EnterBootloader(void) {
  __disable_irq();
  SysTick->CTRL = 0U; SysTick->LOAD = 0U; SysTick->VAL = 0U;
  /* Stop the 100 kHz motion timer at the PERIPHERAL, not just in the NVIC:
   * across the jump it would otherwise keep running with UIF asserted, waiting
   * to ambush the next image the moment it unmasks the shared vector. */
  TIM9->CR1 = 0U; TIM9->DIER = 0U; TIM9->SR = 0U;
  /* Same class of hazard, second offender: the RS-485 RX runs on circular DMA.
   * Left enabled across the jump, the stream keeps draining USART1->DR into
   * this (dead) image's ring buffer — the bootloader's polled RX then never
   * sees RXNE and the update CLI is deaf. Tear it down at the peripheral. */
  USART1->CR3 &= ~USART_CR3_DMAR;
  DMA2_Stream2->CR &= ~DMA_SxCR_EN;
  while (DMA2_Stream2->CR & DMA_SxCR_EN) { }
  for (int i = 0; i < 8; i++) { NVIC->ICER[i] = 0xFFFFFFFFU; NVIC->ICPR[i] = 0xFFFFFFFFU; }
  uint32_t sp = *(volatile uint32_t *)BL_BASE_ADDR;
  uint32_t pc = *(volatile uint32_t *)(BL_BASE_ADDR + 4U);
  __set_CONTROL(0);                 /* leave the FreeRTOS task PSP — run on MSP */
  __ISB();
  SCB->VTOR = BL_BASE_ADDR;
  __set_MSP(sp);
  __DSB(); __ISB();
  __enable_irq();                   /* bootloader needs SysTick/flash IRQs; none pending */
  ((void (*)(void))pc)();
  while (1) { }                     /* not reached */
}

/* ------------------------------------------------------------------------- */
/* Clock-tree constraints, enforced at compile time.                         */
/*                                                                           */
/* Getting HSE_VALUE or PLLM wrong is silent at build time but breaks every   */
/* derived clock (UART baud, SPI SCK, timer rates) — and this project inherits */
/* its clock code from a board with a DIFFERENT crystal, so the mistake is a  */
/* realistic one. These assertions make it a build error instead.            */
/* Limits are from RM0383 (PLL) and DS10314 (max frequencies).               */
/* ------------------------------------------------------------------------- */
#define CFG_PLLM        8U
#define CFG_PLLN        100U
#define CFG_PLLP        2U
#define CFG_PLL_VCO_IN  (HSE_VALUE / CFG_PLLM)
#define CFG_PLL_VCO_OUT (CFG_PLL_VCO_IN * CFG_PLLN)
#define CFG_SYSCLK      (CFG_PLL_VCO_OUT / CFG_PLLP)

_Static_assert(HSE_VALUE == 16000000U,
               "Board crystal X1 is 16 MHz (X322516MLB4SI) - check -D HSE_VALUE");
_Static_assert(CFG_PLL_VCO_IN >= 1000000U && CFG_PLL_VCO_IN <= 2000000U,
               "PLL input (HSE/PLLM) must be 1-2 MHz, 2 MHz recommended");
_Static_assert(CFG_PLL_VCO_OUT >= 100000000U && CFG_PLL_VCO_OUT <= 432000000U,
               "PLL VCO output must be 100-432 MHz");
_Static_assert(CFG_SYSCLK == 100000000U,
               "SYSCLK must be 100 MHz (STM32F411 maximum)");

/**
  * @brief  The application entry point.
  */
int main(void)
{
  /* IAP: this image runs from the Exec region (0x08020000). Copy the vector table into
   * RAM and point VTOR at it (before HAL_Init, so the HAL/NVIC use it): keeping vectors
   * in RAM means interrupt entry never fetches from flash, so the motion ISR keeps firing
   * during a flash erase/program (settings/bank save/network update). */
  for (uint32_t i = 0; i < 128U; i++)
    g_ramVectors[i] = ((const volatile uint32_t *)APP_EXEC_BASE)[i];
  SCB->VTOR = (uint32_t)g_ramVectors;
  __DSB();
  __ISB();

  /* A bootloader JUMP (the `update`/`boot` chain) does not reset peripherals:
   * the PREVIOUS app's TIM9 arrives still running with its update interrupt
   * asserted. The first NVIC enable of that line would fire the motion ISR
   * before RampsData's timer handles are wired — a NULL deref chain ending in
   * a bus fault (found the hard way over RS-485 YMODEM update on the bench).
   * Quiesce it before interrupts come on. Gated on the clock: after a real
   * reset TIM9 is unclocked and already quiet. */
  if (RCC->APB2ENR & RCC_APB2ENR_TIM9EN) {
    TIM9->CR1  = 0U;
    TIM9->DIER = 0U;
    TIM9->SR   = 0U;
  }

  /* The IAP bootloader hands off with a JUMP and PRIMASK set (bl_jump_to_exec
   * does __disable_irq() and never re-enables). Without this, the whole of
   * main() runs with the HAL tick frozen — every HAL timeout is infinite, so a
   * misbehaving peripheral (e.g. a hung I2C bus in AoutInit) wedges the boot —
   * until osKernelStart()'s cpsie finally unmasks interrupts. On a clean
   * power-on reset PRIMASK is already clear and this is a no-op. */
  __enable_irq();

  /* Reset of all peripherals, initializes the Flash interface and the Systick. */
  HAL_Init();

  /* Configure the system clock */
  SystemClock_Config();

  /* Initialize all configured peripherals */
  MX_GPIO_Init();
  MX_TIM1_Init();
  MX_TIM2_Init();
  MX_TIM3_Init();
  MX_TIM4_Init();
  MX_TIM5_Init();
  MX_USART1_UART_Init();
  MX_I2C1_Init();
  MX_TIM9_Init();
  // htim1..htim5 count the five encoder scales (quadrature)
  // htim9 generates the 100 kHz synchro motion interrupt
  // i2c1 carries the GP8403 analog-out DAC (+ the DB9 expansion bus)

  DebugPrint("\r\ndrDRO mainboard V1.5 (STM32F411RET6) " FW_VERSION "\r\n");

  RampsData.shared.scales[0].timerHandle = &htim1;
  RampsData.shared.scales[1].timerHandle = &htim2;
  RampsData.shared.scales[2].timerHandle = &htim3;
  RampsData.shared.scales[3].timerHandle = &htim4;
  RampsData.shared.scales[4].timerHandle = &htim5;
  RampsData.synchroRefreshTimer = &htim9;
  RampsData.commUart = &huart1;
  RampsStart(&RampsData);

  /* Override compiled defaults with persisted settings (scales ratios, servo cfg,
   * aout/net/din config) if a valid image is present in flash. Before the
   * scheduler starts. */
  SettingsApply(&RampsData.shared);

  /* The encoder timers were started by RampsStart with the compiled-in filter;
   * reprogram them with the persisted per-scale value. */
  for (int i = 0; i < SCALES_COUNT; i++)
    setScaleFilter(RampsData.shared.scales[i].timerHandle, RampsData.shared.scales[i].filterValue);

  /* Persisted RS-485 baud (com.baud): sanitize, then re-init USART1 if it
   * differs from the 115200 default the banner just went out at. Safe here:
   * protocol RX isn't armed until the scheduler starts. The BOOTLOADER always
   * talks 115200 — recovery must not depend on a setting — so update tooling
   * switches rates between the app and bootloader phases. */
  if (RampsData.shared.comBaud < 9600U || RampsData.shared.comBaud > 2000000U)
    RampsData.shared.comBaud = 115200U;
  if (RampsData.shared.comBaud != huart1.Init.BaudRate) {
    huart1.Init.BaudRate = RampsData.shared.comBaud;
    if (HAL_UART_Init(&huart1) != HAL_OK) {
      huart1.Init.BaudRate = 115200U;          /* never brick the console */
      (void)HAL_UART_Init(&huart1);
    }
  }

  /* Digital inputs: pull-ups + debounce poll task. The task ALSO brings up the
   * GP8403 analog outputs — deliberately NOT done here: from the first
   * osThreadNew above until osKernelStart, FreeRTOS holds BASEPRI at the
   * syscall mask, so the TIM11 HAL tick is frozen and any blocking HAL call
   * (I2C!) has an infinite timeout. A hung DAC here = a bricked boot. */
  DinStart(&RampsData.shared);

  /* Init the RTOS. (Tasks were created in RampsStart — same order as the proven
   * baseline: xTaskCreate is legal before the scheduler starts.) */
  osKernelInitialize();

  /* SPI2 + the W5500 are brought up inside the net task (it needs osDelay for
   * the reset timing and blocks on DHCP). Reports state via gBlinkCode and the
   * net.* registry variables; honors the persisted static-IP config. */
  NetStart(&RampsData.shared);

  /* TCP CLI: the same line protocol as RS-485, on port net.port (default 5555). */
  NetCliStart(&RampsData.shared);

  /* Network firmware update: fw.* commands stream an image into the inactive
   * bank on port net.port+1; the bootloader activates it on the next reset. */
  FwUpdateStart(&RampsData.shared);

  osKernelStart();

  /* Control is now with the scheduler; never reached. */
  while (1)
  {
  }
}

/**
  * @brief System Clock Configuration
  *
  * HSE = 16 MHz crystal (X1 = X322516MLB4SI, per the board netlist).
  *
  *   PLL input   = HSE / PLLM = 16 MHz / 8   = 2 MHz   (VCO input must be 1-2 MHz)
  *   VCO         = 2 MHz * PLLN = 2 * 100    = 200 MHz
  *   SYSCLK      = VCO / PLLP = 200 / 2      = 100 MHz (F411 maximum)
  *   PLLQ output = VCO / 4                   = 50 MHz  (USB/SDIO — unused here)
  *
  * NOTE this differs from the F4 baseline project, which has an 8 MHz crystal and
  * therefore uses PLLM = 4. Keeping PLLM = 4 here would give a 4 MHz VCO input
  * and a 200 MHz SYSCLK request — out of spec and it would not run.
  *
  * AHB = 100 MHz, APB1 = 50 MHz (SPI2), APB2 = 100 MHz (USART1, TIM9).
  * Flash latency 3 WS is correct for 100 MHz at 3.3 V.
  */
void SystemClock_Config(void)
{
  RCC_OscInitTypeDef RCC_OscInitStruct = {0};
  RCC_ClkInitTypeDef RCC_ClkInitStruct = {0};

  /** Configure the main internal regulator output voltage */
  __HAL_RCC_PWR_CLK_ENABLE();
  __HAL_PWR_VOLTAGESCALING_CONFIG(PWR_REGULATOR_VOLTAGE_SCALE1);

  /** Initializes the RCC Oscillators */
  RCC_OscInitStruct.OscillatorType = RCC_OSCILLATORTYPE_HSE;
  RCC_OscInitStruct.HSEState = RCC_HSE_ON;
  RCC_OscInitStruct.PLL.PLLState = RCC_PLL_ON;
  RCC_OscInitStruct.PLL.PLLSource = RCC_PLLSOURCE_HSE;
  RCC_OscInitStruct.PLL.PLLM = CFG_PLLM;   /* 8 for the 16 MHz HSE (was 4 @ 8 MHz) */
  RCC_OscInitStruct.PLL.PLLN = CFG_PLLN;
  RCC_OscInitStruct.PLL.PLLP = RCC_PLLP_DIV2;   /* == CFG_PLLP */
  RCC_OscInitStruct.PLL.PLLQ = 4;
  if (HAL_RCC_OscConfig(&RCC_OscInitStruct) != HAL_OK)
  {
    Error_Handler();
  }

  /** Initializes the CPU, AHB and APB buses clocks */
  RCC_ClkInitStruct.ClockType = RCC_CLOCKTYPE_HCLK|RCC_CLOCKTYPE_SYSCLK
                              |RCC_CLOCKTYPE_PCLK1|RCC_CLOCKTYPE_PCLK2;
  RCC_ClkInitStruct.SYSCLKSource = RCC_SYSCLKSOURCE_PLLCLK;
  RCC_ClkInitStruct.AHBCLKDivider = RCC_SYSCLK_DIV1;
  RCC_ClkInitStruct.APB1CLKDivider = RCC_HCLK_DIV2;
  RCC_ClkInitStruct.APB2CLKDivider = RCC_HCLK_DIV1;

  if (HAL_RCC_ClockConfig(&RCC_ClkInitStruct, FLASH_LATENCY_3) != HAL_OK)
  {
    Error_Handler();
  }
}

/**
  * @brief  Period elapsed callback — TIM11 drives the HAL timebase (SysTick
  *         belongs to FreeRTOS; SysTick_Handler lives in cmsis_os2.c).
  */
void HAL_TIM_PeriodElapsedCallback(TIM_HandleTypeDef *htim)
{
  if (htim->Instance == TIM11) {
    HAL_IncTick();
  }
}

/**
  * @brief  This function is executed in case of error occurrence.
  */
void Error_Handler(void)
{
  __disable_irq();
  while (1)
  {
  }
}

#ifdef  USE_FULL_ASSERT
void assert_failed(uint8_t *file, uint32_t line)
{
}
#endif /* USE_FULL_ASSERT */

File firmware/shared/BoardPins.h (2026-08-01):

/**
 * BoardPins.h — drDRO mainboard V1.5 pin map (STM32F411RET6, LQFP-64).
 *
 * Authoritative source: the board netlist (Netlist_Schematic1_2026-07-10.net,
 * U6 = STM32F411RET6 / LCSC C94355), cross-checked against ../docs/mcu_pinmap.md.
 *
 * DO NOT copy pin assignments from ../../drdro-firmware-f4 — that project targets
 * a different board (STM32F411CEU6, LQFP-48) and several pins moved. Notably its
 * user LED is on PB12, which on THIS board is the W5500 chip-select.
 *
 * Package pin numbers are given so each line can be traced back to the netlist.
 */
#ifndef __BOARD_PINS_H
#define __BOARD_PINS_H

/* ------------------------------------------------------------------------- */
/* Status LED (LED3)                                                          */
/*                                                                            */
/* Net $1N6826: LED3 cathode -> PA12 (pin 45); LED3 anode -> R13 -> 3V3.       */
/* => ACTIVE LOW. Drive the pin LOW to light the LED.                         */
/* ------------------------------------------------------------------------- */
#define USR_LED_GPIO_Port        GPIOA
#define USR_LED_Pin              GPIO_PIN_12
#define USR_LED_ON_STATE         GPIO_PIN_RESET
#define USR_LED_OFF_STATE        GPIO_PIN_SET

/* ------------------------------------------------------------------------- */
/* W5500 Ethernet (U19) — SPI2, AF5                                           */
/*                                                                            */
/* SCSn is driven as a software GPIO (SPI2 SSM=1/SSI=1), NOT hardware NSS: the */
/* W5500 needs SCSn asserted for the whole variable-length (VDM) transaction.  */
/* See docs/STATUS.md "FIRMWARE notes" and docs/board_review_todo.md.          */
/* ------------------------------------------------------------------------- */
#define W5500_SPI                SPI2
#define W5500_SPI_GPIO_Port      GPIOB
#define W5500_SCK_Pin            GPIO_PIN_13   /* pin 34, SPI_SCK  -> U19-33 */
#define W5500_MISO_Pin           GPIO_PIN_14   /* pin 35, SPI_MISO -> U19-34 */
#define W5500_MOSI_Pin           GPIO_PIN_15   /* pin 36, SPI_MOSI -> U19-35 */
#define W5500_SPI_AF             GPIO_AF5_SPI2

#define W5500_CS_GPIO_Port       GPIOB
#define W5500_CS_Pin             GPIO_PIN_12   /* pin 33, SPI_NSS  -> U19-32 (R72 10k pull-up) */

#define W5500_RST_GPIO_Port      GPIOC
#define W5500_RST_Pin            GPIO_PIN_7    /* pin 38, SPI_RST  -> U19-37 (R70 pull-up), active low */

#define W5500_INT_GPIO_Port      GPIOC
#define W5500_INT_Pin            GPIO_PIN_6    /* pin 37, SPI_INT  -> U19-36 (R71 pull-up), active low */

/* ------------------------------------------------------------------------- */
/* RS-485 host link (U5 = SP3485EN) — USART1, AF7                             */
/*                                                                            */
/* No hardware driver-enable on the F411: DE is a plain GPIO, asserted before  */
/* TX and released in the USART TC interrupt.                                 */
/* ------------------------------------------------------------------------- */
#define RS485_UART               USART1
#define RS485_TX_GPIO_Port       GPIOA
#define RS485_TX_Pin             GPIO_PIN_15   /* pin 50, UART_TX -> U5-4 (DI) */
#define RS485_RX_GPIO_Port       GPIOA
#define RS485_RX_Pin             GPIO_PIN_10   /* pin 43, UART_RX -> U5-1 (RO) */
#define RS485_UART_AF            GPIO_AF7_USART1

#define RS485_DE_GPIO_Port       GPIOA
#define RS485_DE_Pin             GPIO_PIN_11   /* pin 44, UART_DE -> U5-2 (/RE) + U5-3 (DE) */

/* ------------------------------------------------------------------------- */
/* Encoders — hardware quadrature, 5 axes on 5 distinct timers.                */
/*                                                                            */
/* NOTE ENC5 must use TIM5 (AF2): PA0/PA1 are also TIM2 CH1/CH2, but TIM2 =    */
/* ENC2. The AM26LV32E receivers land A+ on the B input pin (consistent across */
/* all five channels), so raw counts run backwards — compensated once in       */
/* Scales.c by inverting the TI1 capture polarity (see initScaleTimer).        */
/*   ENC1 A/B = PA8/PA9  (41/42)  TIM1 CH1/CH2 (AF1)   U7  = J1                */
/*   ENC2 A/B = PA5/PB3  (21/55)  TIM2 CH1/CH2 (AF1)   U8  = J2                */
/*   ENC3 A/B = PA6/PA7  (22/23)  TIM3 CH1/CH2 (AF2)   U9  = J3                */
/*   ENC4 A/B = PB6/PB7  (58/59)  TIM4 CH1/CH2 (AF2)   U10 = J4                */
/*   ENC5 A/B = PA0/PA1  (14/15)  TIM5 CH1/CH2 (AF2)   U11 = J5                */
/* ------------------------------------------------------------------------- */
#define ENC1_GPIO_Port           GPIOA
#define ENC1_A_Pin               GPIO_PIN_8    /* pin 41, TIM1_CH1 */
#define ENC1_B_Pin               GPIO_PIN_9    /* pin 42, TIM1_CH2 */
#define ENC1_AF                  GPIO_AF1_TIM1
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

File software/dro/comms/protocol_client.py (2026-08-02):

"""drDRO line-protocol client over RS-485.

Replaces the Modbus `ConnectionManager`. Talks the firmware's custom CLI line protocol
(see ../drdro-firmware-f4/docs/protocol_design.md):

  request  : ``command [args] [*HH]\\r``      (``*HH`` = optional XOR-8 hex of the body)
  response : ``key=value\\n`` lines, then ``crc=HH\\n`` (XOR-8 of the body), then a blank line.
             An ``error=<reason>`` line means the command failed.
  arrays   : one comma-joined line, e.g. ``scales.pos=12345,988,0,42``.

Concurrency (design D3): a single half-duplex bus means only one command may be outstanding
at a time. The public API is **async** and guarded by an :class:`asyncio.Lock`; the blocking
pyserial I/O runs in a dedicated single-thread executor, so the Kivy event loop is never
blocked. The protocol benches >100 Hz, leaving headroom to interleave ``set``/``get``/``save``
between 30 Hz ``sta`` polls.

Resilience mirrors the old ConnectionManager: a transient glitch does not bounce the link;
the connection is only declared down after ``max_errors`` consecutive failures. The RS-485
auto-direction transceiver can drop the firmware's first TX byte after a long RX, which can
make a valid command look like ``unknown command``/``unknown variable`` — those (and any
CRC/framing failure) are retried; genuine protocol errors (``read-only``, ``bad index``,
``value out of range``) are returned as-is.
"""
from __future__ import annotations

import asyncio
import logging
import time
from concurrent.futures import ThreadPoolExecutor
from dataclasses import dataclass, field

import serial

log = logging.getLogger(__name__)

# Errors that are likely an RS-485 turnaround glitch (dropped byte) rather than a real answer.
_GLITCH_ERRORS = frozenset({"unknown command", "unknown variable"})


def xor8(data: bytes) -> int:
    """NMEA-style XOR-8 checksum over ``data``."""
    c = 0
    for b in data:
        c ^= b
    return c


def frame_request(text: str, checksum: bool = False) -> bytes:
    """Encode a command line for the wire: optional ``*HH`` suffix, ``\\r`` terminated."""
    body = text.encode("ascii")
    if checksum:
        return body + b"*" + f"{xor8(body):02X}".encode("ascii") + b"\r"
    return body + b"\r"


@dataclass
class Response:
    """A parsed protocol response frame.

    ``crc_ok`` reflects link/frame health (a well-formed, checksum-valid reply was received),
    independent of ``error`` — a CRC-valid ``error=read-only`` is a healthy link with a
    negative answer. Truthiness = a valid frame with no ``error`` line.
    """

    lines: list[str] = field(default_factory=list)   # body lines incl. the trailing crc= line
    values: dict[str, str] = field(default_factory=dict)
    error: str | None = None
    crc_ok: bool = False

    def __bool__(self) -> bool:
        return self.crc_ok and self.error is None

    # ── typed accessors ──────────────────────────────────────────────
    def text(self, key: str) -> str | None:
        return self.values.get(key)

    def as_int(self, key: str) -> int | None:
        v = self.values.get(key)
        return int(v) if v is not None else None

    def as_float(self, key: str) -> float | None:
        v = self.values.get(key)
        return float(v) if v is not None else None

    def as_ints(self, key: str) -> list[int]:
        v = self.values.get(key)
        return [int(x) for x in v.split(",")] if v else []

    def as_floats(self, key: str) -> list[float]:
        v = self.values.get(key)
        return [float(x) for x in v.split(",")] if v else []


def parse_response(lines: list[str]) -> Response:
    """Parse the lines of one frame (body lines incl. the trailing ``crc=HH`` line)."""
    if not lines or not lines[-1].startswith("crc="):
        # No terminating crc line → incomplete/garbled frame (timeout or glitch).
        values, error = _split_kv(lines)
        return Response(lines=lines, values=values, error=error, crc_ok=False)

    body = "".join(l + "\n" for l in lines[:-1])
    try:
        want = int(lines[-1].split("=", 1)[1], 16)
    except ValueError:
        want = -1
    crc_ok = want == xor8(body.encode("ascii"))

    values, error = _split_kv(lines[:-1])
    return Response(lines=lines, values=values, error=error, crc_ok=crc_ok)


def _split_kv(lines: list[str]) -> tuple[dict[str, str], str | None]:
    values: dict[str, str] = {}
    error: str | None = None
    for line in lines:
        if "=" not in line:
            continue
        key, val = line.split("=", 1)
        if key == "crc":
            continue
        if key == "error":
            error = val
        values[key] = val
    return values, error


def _read_frame(ser, timeout: float) -> list[str]:
    """Read one framed response: body ``key=value`` lines until a blank line.

    Returns the body lines *including* the trailing ``crc=HH`` line. On timeout returns
    whatever was collected (possibly empty/partial), which :func:`parse_response` flags
    as ``crc_ok=False``.
    """
    deadline = time.monotonic() + timeout
    buf = b""
    lines: list[str] = []
    seen = False
    while time.monotonic() < deadline:
        c = ser.read(1)
        if not c:
            continue
        if c == b"\n":
            line = buf.decode("ascii", "replace").replace("\r", "").strip()
            buf = b""
            if line == "":
                if seen:
                    return lines
                continue          # leading blank/glitch before any content
            seen = True
            lines.append(line)
        else:
            buf += c
    return lines


def _fmt(value) -> str:
    """Format a Python value for a ``set`` argument."""
    if isinstance(value, bool):
        return str(int(value))
    if isinstance(value, float):
        return f"{value:.10g}"
    return str(value)


class ProtocolError(Exception):
    """Raised for client-side protocol/usage errors (not firmware ``error=`` replies)."""
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

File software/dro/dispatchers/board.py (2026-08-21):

"""Board dispatcher — owns the RS-485 line-protocol link and bridges it to the Kivy UI.

Replaces the Modbus `ConnectionManager`/`device[...]` register model with the async
`ProtocolClient` (dro.comms). The bridge between the synchronous Kivy/dispatcher world and
the async client:

- A single **async poll loop** (`run`) issues `sta` at ~30 Hz, maps the reply into
  `fast_data_values` (keeping the field names the dispatchers already use), bumps the
  `update_tick` Kivy property, and tracks `connected`. Low-rate `diag.*` is folded in.
- Synchronous dispatcher callbacks issue writes via `write()` / `write_persisted()`, which
  schedule the async `set` (and a debounced `save`) on the running loop — never blocking.
- On (re)connect the board reads the full `settings` dump into a cache; `cached()` serves the
  occasional synchronous reads (e.g. sync-enable state) the dispatchers need.

Settings model (design §D): the firmware is the source of truth for `servo.max/acc/jog/idx`
(read on connect, `set`+`save` on UI change); dynamic ratios `scales.num/den` are pushed
live and never saved; `scales.sync`/`servo.mode` are live operational state.
"""
import asyncio
import os
import time

import serial

from kivy.clock import Clock
from kivy.event import EventDispatcher
from kivy.properties import NumericProperty, BooleanProperty, ObjectProperty, ListProperty, StringProperty

from dro.comms.protocol_client import ProtocolClient, ProtocolError, Response
from dro.dispatchers.axis import AxisDispatcher
from dro.dispatchers.axis_transform import AxisTransform
from dro.dispatchers.input import InputDispatcher
from dro.dispatchers.saving_dispatcher import SETTINGS_FOLDER, read_settings
from dro.dispatchers.servo import ServoDispatcher
from dro.utils.constants import SCALES_COUNT
from dro.utils.fw_compat import fw_update_required, mismatch_message
from dro.utils.version import installed_version

from kivy.logger import Logger
log = Logger.getChild(__name__)


def map_sta(resp: Response) -> dict:
    """Map an `sta` response to the legacy `fast_data_values` dict the dispatchers consume.

    Keeps the old field names so the dispatcher tick handlers port unchanged:
      scaleCurrent/scaleSpeed (4-arrays), servoCurrent, servoSpeed, stepsToGo, servoEnable.
    (`servoEnable` is the firmware's 0/1/2 servoMode — identical semantics.)
    """
    return {
        "scaleCurrent": resp.as_ints("scales.pos") or [0] * SCALES_COUNT,
        "scaleSpeed": resp.as_ints("scales.speed") or [0] * SCALES_COUNT,
        "servoCurrent": resp.as_int("servo.pos") or 0,
        "servoSpeed": resp.as_float("servo.speed") or 0.0,
        "stepsToGo": resp.as_int("servo.tgt") or 0,
        "servoEnable": resp.as_int("servo.mode") or 0,
    }


class Board(EventDispatcher):
    connected = BooleanProperty(False)
    update_tick = NumericProperty(0)
    scale_count = NumericProperty(SCALES_COUNT)      # inputs the connected board reports (scales.count)
    firmware_version = StringProperty("")            # cached on (re)connect (Stats screen, banner)
    # One version for the whole stack: the board's firmware must EQUAL the installed
    # software version. Anything else (older or newer) is an incoherent stack the user is
    # asked to realign — see dro.utils.fw_compat.
    firmware_update_required = BooleanProperty(False)
    firmware_mismatch = StringProperty("")           # user-facing reason, "" when coherent
    blink = BooleanProperty(False)
    servo = ObjectProperty(None, allownone=True)
    inputs = ListProperty()
    axes = ListProperty()

    def __init__(self, formats, offset_provider, *, transport="serial",
                 port="/dev/serial0", baudrate=115200, host="", tcp_port=5555,
                 poll_period=1.0 / 50, save_debounce=0.75, software_version=None, **kv):
        super().__init__(**kv)
        self.formats = formats
        self.offset_provider = offset_provider
        self.fast_data_values = dict()
        # The version this stack is supposed to be on; the board must report the same.
        # Injectable so tests can drive the coherence rule without touching package metadata.
        self.software_version = software_version or installed_version()

        # One line protocol, two pipes: RS-485 (pyserial) or Ethernet (TCP). A blank tcp host
        # stays disconnected until the user sets the board IP in the Connection setup page.
        if transport == "tcp":
            self.connection = ProtocolClient(host=host or "", tcp_port=tcp_port)
        else:
            self.connection = ProtocolClient(port, baudrate=baudrate)
        self._poll_period = poll_period
        self._save_debounce = save_debounce
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

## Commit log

2026-07-04 Add drDRO mainboard design notes, pin map, and netlist
    Consolidated review docs for the 24V->5V power stage, universal encoder
    front-end, RS-485, W5500 Ethernet, and full MCU pin-function audit.
    STATUS.md is the authoritative resume point; netlist as of 2026-07-04.
2026-07-05 Sync design/tracker docs with current netlist (171 comp / 133 nets)
    Re-verified the 2026-07-04 export end-to-end (zero dangling nets) and
    reconciled the docs with actual board state:
    - STATUS.md: encoders demoted done->in-progress (3-chip A/B built; the
    5-chip-per-DB9 + index-Z restructure is still owed); re-verify stamp;
    fixed document index.
    - mcu_pinmap.md: motor pins PD2/PB4/PB5/PC13 -> PC0/PC1/PC2/PC3; SPI2 now
    wired to W5500; MCU VDD/VSS pins 18/19 fixed; corrected free-GPIO list;
    updated JTAG note (PB4 freed).
    - encoder_input_design.md: added as-built-vs-target section + Z-routing
    constraint (only DB9 pin 6 free; 11 free MCU GPIOs available).
    - encoder_input_todo.md: rewrit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
2026-07-09 Add 2026-07-09 re-review: 5-chip encoder split, layout review, part changes
    Full adversarial re-review against Netlist_PCB1_2026-07-09.net (177 comp /
    133 nets, zero dangling, zero shorts) plus a first PCB layout review of
    Gerber_PCB1_2026-07-09.zip.
    - Encoder front-end: 5-chip-per-DB9 split done (U7=J1 … U11=J5, AM26LV32E,
    A/B only); index-Z descoped -> front-end final
    - I2C expansion bus pull-ups added (R14/R74 4.7k); SPI NSS pull-up added (R72)
    - RS485: U5 SIT3088 (OOS) -> SP3485EN-L/TR drop-in, DFN-8 -> SOIC-8
    - TVS: replace D1 -> SMCJ30A; add SMAJ6.0CA ESD/surge on IN1-6 (open)
    - Layout: 4-layer, solid GND plane, buck EP stitched, receivers at DB9s;
    open items on Inner2 plane net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
2026-07-11 Add 2× 0–10 V analog outputs, place RS485 SP3485EN, final pre-order Gerber
    Final pre-order review of the 4-layer board. Netlist, Gerber, and the EasyEDA
    .epro2 project all cross-check as the same current design (189 comp / 138 nets,
    zero dangling, all rails/EP resolved).
    Analog outputs (new):
    - U20 GP8403 dual 12-bit I2C DAC (C3152007) -> 2× 0–10 V for VFD speed reference
    - VCC=VIN(24V), EP->GND, on shared I2C1 (PB8/PB9, addr 0x58, R14/R74 reused)
    - VOUT0->AO0 / VOUT1->AO1, each 1uF + SMAJ12A TVS (C113957) + 47R -> CN9
    - 4–20 mA option dropped; caps 1uF per official GP8403 datasheet
    - design + phased tracker: analog_output_design.md / analog_output_todo.md
    RS485: U5 SP3485EN-L/TR (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
2026-07-11 Final routing pass: re-exported Gerber + rename project to V1.5 Final
    Layout-only revision (Gerber 01:50) on the same verified design — flying-probe
    connectivity re-checked and unchanged: all parts present (U5/U6/U7–U11/U19/U20),
    no stray muxes, Ethernet diff pairs intact to magjack J6, U5 pinout correct,
    U20 VCC=VIN/EP→GND. Stackup JLC04161H-7628 + 0.2mm (100R) diff pairs retained;
    min via 0.305mm / min trace 8mil / board 178.05×75.69mm unchanged.
    - update Gerber_PCB1_2026-07-11.zip with the final routing (drop download suffix)
    - rename EasyEDA project -> "V1.5 Final" (was mis-named "V1.4 2 Layer")
    - keep Netlist_Schematic1_2026-07-10.net (connectivity unaffected by re-route)
    - STAT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
2026-07-28 add models for enclosure
    [bottom-shell.step, top-cover.step]
2026-08-01 chore: add devcontainer and editor tooling
    PlatformIO + ST-Link toolchain in a container (WSL USB passthrough, host
    networking for board access), VS Code tasks for both firmware projects.
2026-08-01 feat: full V1.5 firmware — app, IAP bootloader, Ethernet CLI and updates
    Port of the drdro-firmware-f4 baseline to the STM32F411RET6 mainboard:
    5 quadrature scales (TIM1-5), step/dir servo axis, registry line protocol
    served over RS-485 (DE on PA11) and TCP (W5500, port 5555), dual-bank IAP
    bootloader with YMODEM recovery, firmware updates over Ethernet into the
    inactive bank, GP8403 analog outputs, opto inputs, DRO2 persistent settings,
    host tools (dro_update.py serial+net) and a 71-case native test suite.
2026-08-01 ci: build/test workflow and semantic-release automation
    CI builds both firmware projects and runs the native tests on every push.
    Pushes to master release via python-semantic-release when tests pass:
    version tag, regenerated CHANGELOG.md, release notes, and the firmware
    assets (app/bootloader/factory images + checksums) attached.
2026-08-01 fix(release): regenerate CHANGELOG.md on every release
    psr 10 defaults to update-mode, which skips a changelog file that lacks its
    insertion flag — v1.0.0 released without the changelog commit. Init mode
    regenerates the file from history and back-fills past releases.
2026-08-01 feat(protocol): report encoder count as read-only scales.count
    Lets the host software size its UI from the board instead of hardcoding it.
2026-08-01 fix(boot): survive a hung I2C bus at startup
    Three stacked issues found when a reset mid-transaction wedged the GP8403:
    the bootloader jumped to the app with PRIMASK set, FreeRTOS masks the HAL
    tick from the first task creation until the scheduler starts, and the DAC
    bring-up ran blocking I2C in exactly those windows — an infinite timeout,
    bricking boot. IRQs are now unmasked on both sides of the handoff, the
    GP8403 init moved into task context (bounded timeouts, degrades to
    error=i2c), and I2C1 init got 9-clock bus recovery plus the F4 errata
    SWRST to clear a latched BUSY.
    [Din.c, main.c]
2026-08-01 fix(boot): harden the bootloader-jump path found by RS-485 update testing
    Bench testing the serial update cycle surfaced a chain of latent issues,
    all invisible until real hardware ran the app->bootloader jump:
    - The first tick interrupt fires inside HAL_Init, and the shared
    TIM1/TIM11 vector handled htim1 while its Instance was still NULL: the
    HAL then serviced 'registers' read from the flash alias at address 0
    and could write back there, latching FLASH_SR PGSERR|PGPERR. Guard the
    shared handlers; whether it bites depends on the bootloader's binary
    content at 0x0800000C — the baseline had the same code and got lucky.
    - Those latched flags survive the jump and made the bootloade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
    [FwUpdate.c, SettingsStore.c, bl_cli.c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]
2026-08-01 feat(protocol): configurable RS-485 baud up to 1 Mbaud (com.baud)
    Persisted setting applied at boot (default 115200); the bootloader stays
    fixed at 115200 so recovery never depends on a setting, and dro_update.py
    switches rates between the app and bootloader phases.
    Making high baud actually work took three structural changes, all
    bench-verified at 1 Mbaud (1000x sta: zero errors, 7 ms median, 142 Hz):
    - RX moved from per-byte interrupts to circular DMA drained by the
    protocol task: the per-byte path cost ~5-10 us of HAL+RTOS work per
    byte and collapsed alongside the 100 kHz motion ISR, with overrun
    errors permanently silencing the console (no error callback).
    - Responses now go out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
    [Ramps.h, SettingsStore.c, dro_update.py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]
2026-08-02 chore(software): add drDRO host software — Kivy port with Ethernet transport
    Port of the Kivy DRO/controller UI from drdro-software-f4 into software/, adapted for
    the V1.5 mainboard. Typed `chore` (not `feat`) so it does NOT trigger the firmware
    semantic-release on master — no firmware changed here.
    - comms: TCP transport (dro/comms/tcp_transport.py) alongside RS-485; ProtocolClient
    picks serial vs tcp (host=None vs host=str) and reopens the pipe after a transport
    failure so a dropped/rebooted board reconnects.
    - discovery: pure-asyncio subnet sweep for boards on the CLI port
    (dro/comms/discovery.py) — probe /24 hosts, `version` handshake, return responders.
    - UI: Connection set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
    [board.py, discovery.py]
2026-08-02 chore(hardware): update board project file; remove H723 variant design notes
    - DRDRO Mainboard V1.5.eprj2: updated EasyEDA Pro project file.
    - remove h723_variant/H723_variant_{design,todo}.md (superseded design study).
2026-08-03 feat(update): single-version stack releases with one-step updates
    Software and firmware now ship under a single monorepo tag and update
    together from one button. The board's firmware version must equal the
    installed software version; any difference raises a mismatch warning.
    Release pipeline:
    - root pyproject stamps software/pyproject.toml via version_toml, so one
    tag versions the whole stack; software's own semantic_release config is
    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
2026-08-03 fix(tests): wait for accept() before dropping the mock board connection
    MockBoardServer.drop_current() closed self._active, which the serve thread
    only sets after accept() returns. create_connection() completes as soon as
    the kernel finishes the handshake, so the drop could run first and silently
    close nothing — leaving the client connected and the subsequent reads timing
    out instead of raising.
    test_transport_raises_on_closed_socket therefore passed or failed purely on
    thread scheduling: green on Windows, red on Linux. Surfaced by the new host
    test gate in the release workflow, which runs the suite on ubuntu.
    drop_current() now waits for a connection to be accepted before closing it.
2026-08-03 fix(tests): pin the Kivy window provider so headless runs can't exit(102)
    Kivy probes window providers in order, and the x11 provider wins wherever
    libX11 is installed: it logs "Provider: x11(['window_sdl2'] ignored)",
    talks to Xlib directly — so SDL_VIDEODRIVER=dummy cannot reach it — and
    calls exit(102) when there is no DISPLAY. The process dies mid-collection
    with no traceback and no output at all.
    It only reproduces on hosts that have the X libraries but no X server,
    which is a CI runner and not a bare container or a developer desktop; a
    clean ubuntu:24.04 image passes because it has no libX11 to find. That is
    why the host suite passed everywhere except the new release gate.
    Settin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
2026-08-03 fix(compat): treat PEP 440 and git-tag prerelease spellings as equal
    The same release reaches the app two ways: the firmware reports the git tag
    ("v1.3.0-beta.1"), the host wheel reports PEP 440 metadata ("1.3.0b1").
    parse_fw_version() read the latter as a plain 1.3.0 release, so on any
    prerelease the two never compared equal.
    That is not cosmetic. Every beta would have shown a permanent version
    mismatch banner, and worse, pending_firmware_update() would have discarded
    its own staged image as stale on the reboot — so a prerelease update would
    install the software and then silently never flash the board.
    Version keys now canonicalise the prerelease phase (a/alpha, b/beta,
    rc/c/pre) and ra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
2026-08-20 fix: use ferrite beads with higher stock availability on jlcpcb. fix speed reporting
    [Ramps.h]
